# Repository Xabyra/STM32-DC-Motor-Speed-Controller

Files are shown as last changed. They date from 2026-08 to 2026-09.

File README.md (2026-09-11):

# STM32 Sensorless DC Motor Speed Controller (BEMF Feedback)

<p align="center">
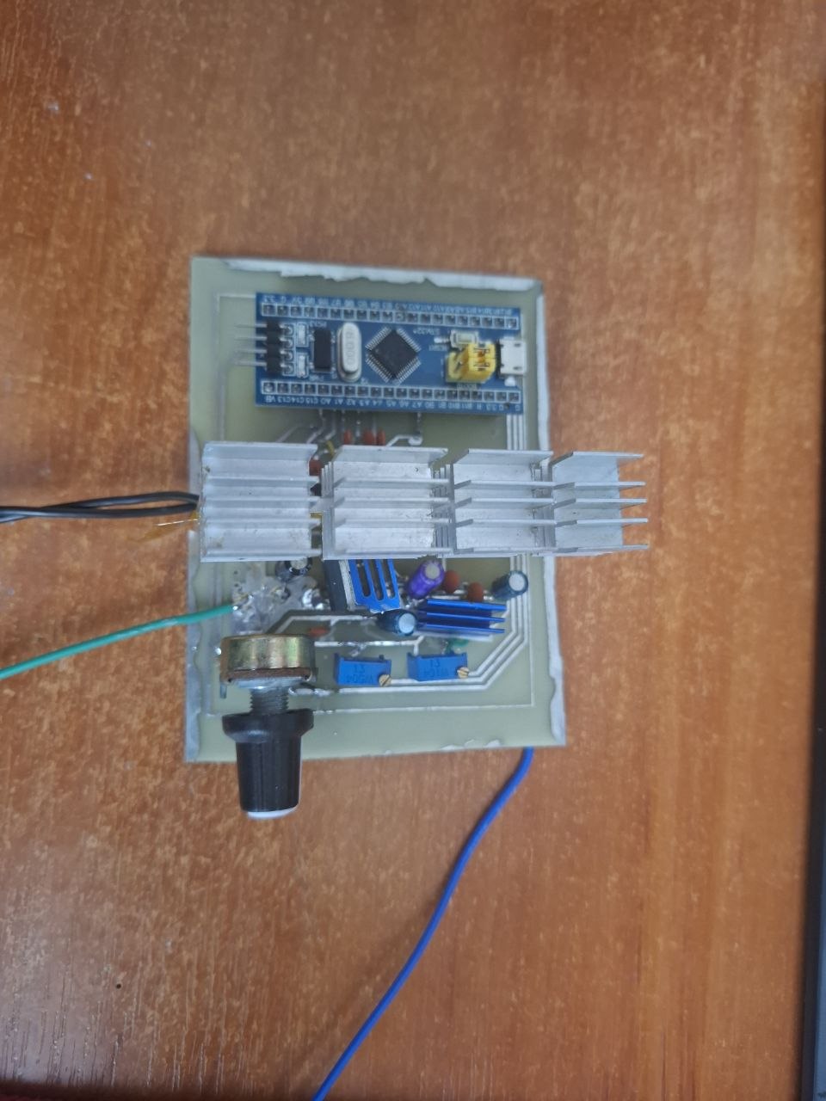
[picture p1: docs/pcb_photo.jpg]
STM32 Motor Controller Board
  
</p>

A closed-loop sensorless brushed DC motor speed regulator using **Back-Electromotive Force (BEMF)** sensing and a digital **PID control algorithm**. Built around the **STM32F103C8** microcontroller with high-speed **SEGGER RTT** real-time telemetry.

---

## ⚡ Key Highlights

* **Sensorless Speed Feedback**: Measures Back-EMF during PWM off-cycles to estimate motor RPM without external optical/magnetic encoders.
* **Closed-Loop PID Regulation**: Real-time RPM stabilization under varying mechanical loads with anti-windup protection.
* **On-the-Fly Tuning**: Live adjustment of PID gains ($K_i$, $K_d$) and target speed via dedicated analog potentiometers.
* **Protection & Smooth Dynamics**: Soft-start speed ramping and undervoltage lockout via continuous motor bus ($V_{MOT}$) monitoring.
* **Non-blocking Telemetry**: High-speed real-time logging via **SEGGER RTT** (J-Link) for control loop inspection without UART latency overhead.

---

## 🛠️ System Overview

### 1. Hardware Architecture (Altium Designer)
Dedicated signal conditioning circuitry with precision resistor dividers for BEMF voltage sensing and power rail filtering.

<p align="center">
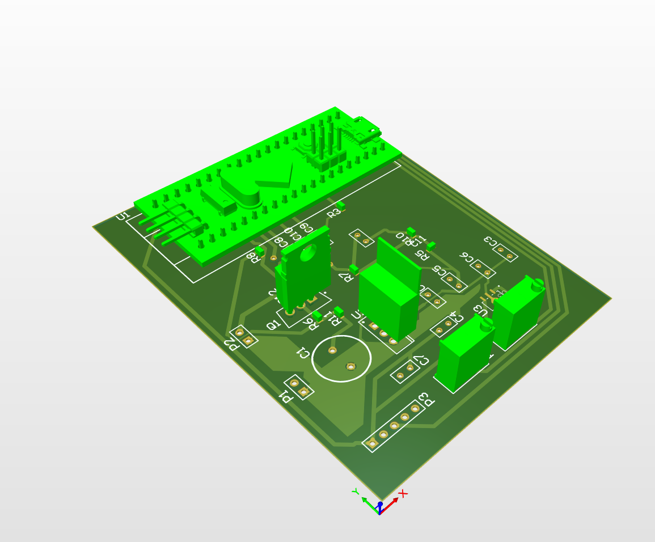
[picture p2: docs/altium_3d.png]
Altium 3D View
  
</p>

* **MCU**: STM32F103C8T6 (ARM Cortex-M3).
* **Power Stage**: H-Bridge motor driver with flyback protection.
* Altium Designer schematics, PCB layouts, and manufacturing Gerbers are located in [`/Hardware`](./Hardware).

---

### 2. Embedded Software (PlatformIO / C++)
* **ADC Sampling**: Synchronized ADC conversions for accurate BEMF and $V_{MOT}$ readings.
* **PWM Generation**: High-frequency timer-driven PWM with configurable duty cycle steps.
* **Control Loop**: Discrete PID controller computing real-time error corrections.

Source code, drivers, and PlatformIO configuration are located in [`/Firmware`](./Firmware).

---

## 📂 Repository Structure

```text
├── Hardware/   # Altium Designer schematics, PCB layout, Gerbers, BOM
├── Firmware/   # PlatformIO source code (C++), drivers, RTT config
└── docs/       # PCB photos, Altium 3D renders, and signal waveforms
```

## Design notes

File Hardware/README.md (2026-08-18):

# DC Motor Regulator with BEMF Feedback
## Software Required

*   **Altium Designer:** You will need Altium Designer (version used for creation or compatible) to open, view, and modify these files.

## Opening the Project

1.  **Install Altium Designer:** Ensure you have Altium Designer installed on your system.
2.  **Clone Repository:** Clone this project to your local machine.
3.  **Open Project File:** Navigate to this `Altium/` directory and open the `.PrjPcb` file (e.g., `DCMotorRegulator.PrjPcb`) using Altium Designer.

## Key Hardware Components

The design typically includes:
*   **STM32F103C8 Microcontroller:** The core processing unit.
*   **Motor Driver:** An H-bridge circuit to control the DC motor (e.g., based on MOSFETs or an integrated driver IC).
*   **Voltage Dividers:** Resistor networks for scaling down the motor voltage (VMOT) and BEMF for ADC input.
*   **Potentiometers:** For user input (target speed, PID tuning).
*   **Power Management:** Voltage regulators to supply the microcontroller and other components.
*   **Connectors:** For motor, power, J-Link, and potentiometers.

## Manufacturing

Once the design is finalized, you can generate manufacturing outputs (Gerber files, NC Drill files, BOM, Pick & Place files) directly from Altium Designer to send to a PCB fabrication house and assembly service.

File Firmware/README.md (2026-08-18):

# Firmware for DC Motor Regulator (PlatformIO)

This directory contains the firmware for the DC Motor Regulator project, developed using PlatformIO with the Arduino framework for the STM32F103C8 microcontroller.

## Project Contents

## Project Overview

The firmware implements the core control logic for regulating a DC motor's speed based on BEMF feedback. It includes:
*   Analog-to-Digital Converter (ADC) readings for BEMF, motor supply voltage (VMOT), target speed, and PID coefficients.
*   Exponential Moving Average (EMA) filters for smoothing sensor readings.
*   A custom PID controller with anti-windup and feedforward capabilities.
*   SEGGER RTT integration for real-time debugging output.

## Requirements

*   **PlatformIO IDE:** Recommended to use the PlatformIO extension for VS Code.
*   **J-Link Debugger:** Required for uploading firmware and utilizing SEGGER RTT.
*   **STM32F103C8 Board:** (e.g., Blue Pill) connected to the J-Link.

## Installation and Setup

1.  **Install PlatformIO:** If you haven't already, install VS Code and the PlatformIO IDE extension.
2.  **Clone Repository:** Clone this project to your local machine.
3.  **Open Project:** Open the `Firmware` directory in VS Code. PlatformIO should automatically detect the project.
4.  **Connect Hardware:**
    *   Connect your STM32F103C8 board to your J-Link debugger (SWD interface).
    *   Ensure the J-Link is connected to your computer.
    *   Refer to the `Docs/Hardware_Connections.md` for detailed wiring instructions.

## Building and Uploading

The `platformio.ini` file is configured for the `genericSTM32F103C8` board and uses `jlink` for upload and debugging.

To build and upload the firmware:
1.  In VS Code, open the PlatformIO sidebar.
2.  Under the "PROJECT TASKS" section for `genericSTM32F103C8`, click on "Build" to compile the code.
3.  After a successful build, click on "Upload" to flash the firmware to your STM32F103C8 board via J-Link.

## SEGGER RTT Debugging

The firmware uses SEGGER RTT for logging and debugging information. This allows you to view real-time output from the microcontroller without halting its execution.

1.  **Start J-Link RTT Viewer:** Open the J-Link RTT Viewer application on your host PC.
2.  **Configure RTT Viewer:**
    *   Select your J-Link device.
    *   Choose "SWD" as the target interface.
    *   Specify the target device (e.g., `STM32F103C8`).
    *   Set the target interface speed (e.g., 4000 kHz).
    *   Click "OK" to connect.
3.  **View Output:** Once connected, you should see the real-time log messages from the microcontroller, including BEMF, target speed, PWM, and PID coefficients.

Example output:
```
RUN | Tar:15000 mV | BEMF:14800 mV | FF:127 | PWM:128/255 | Ki: 50/1000 | Kd: 10/1000
```

## Code Structure (`main.cpp`)

*   **Configuration Defines:** `MAX_TARGET_EMF`, `PID_DIVIDER`, pin assignments, etc.
*   **`IntEMA` Class:** A simple Exponential Moving Average filter for smoothing analog readings.
*   **`PIDreg` Class:** Implements the PID control logic.
*   **`setup()`:** Initializes SEGGER RTT, ADC, PWM, and EMA filters.
*   **`loop()`:** Continuously calls the `control()` function.
*   **`control()`:**
    *   Disables PWM temporarily to measure BEMF.
    *   Reads `VMOT_PIN` and `BEMF_PIN` via voltage dividers.
    *   Filters all analog inputs using EMA.
    *   Calculates PID coefficients from potentiometer readings.
    *   Implements safety checks for `VMOT` and `Target EMF`.
    *   Applies a smooth start to the target speed.
    *   Calculates PWM output using the PID controller and feedforward.
    *   Logs critical data via SEGGER RTT.

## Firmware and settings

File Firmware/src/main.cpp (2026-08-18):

#include <Arduino.h>
#include <SEGGER_RTT.h>

// =========================== CONFIG ===========================
#define MAX_TARGET_EMF 30000  // максимальний BEMF [мВ] 
#define DIV_R1 20000          // верхнє плече дільника [Ом]
#define DIV_R2 2200           // нижнє плече дільника [Ом]
#define PID_DIVIDER 16000.0   

#define MIN_TARGET_EMF 50     // ЗНИЖЕНО: щоб мотор стартував від легкого повороту ручки
#define MIN_VMOT 6000         // мінімальне живлення [мВ] (6В)
#define CTRL_PRD 20           // період управління [мс]
#define WAIT_ADC 800          // пауза після вимкнення ШИМ [мкс]
#define SMOOTH_STEP 100       // крок плавного пуску

#define FIXED_P_RAW 1500      // Фіксований Kp (оскільки ручки зайняті Speed, I, D)

// Піни МК
#define BEMF_PIN  PA0   
#define VMOT_PIN  PA1   
#define SPEED_PIN PA2   // A2 - Скорість (Target)
#define I_PIN     PA3   // A3 - Integral (Ki)
#define D_PIN     PA4   // A4 - Derivative (Kd)
#define PWM_PIN   PB0   

// =========================== DATA ===========================
const int vref = 3300;   // 3.3V
int target = 0;          
int pwm = 0;             

// ========================== IntEMA ==========================
template <typename T>
class IntEMA {
   public:
    T filter(T val, uint8_t k2) {
        T sum = (val - _filt) + _err;
        T div = sum >> k2;
        _err = sum - (div << k2);
        return _filt += div;
    }
    void init(T val) {
        _filt = val;
        _err = 0;
    }
    T get() { return _filt; }
   private:
    T _filt = 0, _err = 0;
};

IntEMA<int> vmot;
IntEMA<int> vemf;
IntEMA<int> a_tar;
IntEMA<int> a_i;
IntEMA<int> a_d;

// =========================== PIDreg ===========================
class PIDreg {
   public:
    float Kp = 0, Ki = 0, Kd = 0;
    float integral = 0;
    float lastError = 0;
    bool firstRun = true;

    int compute(int input, int setpoint, int feedforward, float dt) {
        float error = setpoint - input;
        
        // Інтегральна складова
        float nextIntegral = integral + error * Ki * dt;

        // Диференціальна складова (по похибці)
        float derivative = 0;
        if (!firstRun && dt > 0) {
            derivative = (error - lastError) / dt;
        } else {
            firstRun = false;
        }
        lastError = error;

        // Підсумковий вихід ПІД + FeedForward
        float output = feedforward + (error * Kp) + nextIntegral + (derivative * Kd);

        // Anti-windup (захист інтеграла від переповнення при насиченні PWM)
        if (!((output > 255 && error > 0) || (output < 0 && error < 0))) {
            integral = nextIntegral;
        }

        return constrain((int)output, 0, 255);
    }

    void reset() {
        integral = 0;
        lastError = 0;
        firstRun = true;
    }
};
PIDreg pid;

// =========================== FUNC ===========================

void setPWM(uint8_t duty) {
    analogWrite(PWM_PIN, duty);
}

uint16_t readDivider(uint8_t apin) {
    uint32_t pinMv = (uint32_t)analogRead(apin) * vref / 4096;
    return (pinMv * (DIV_R1 + DIV_R2)) / DIV_R2;
}

void control() {
    static uint32_t tmr;
    if (millis() - tmr < CTRL_PRD) return;
    float dt = (millis() - tmr) / 1000.0f;
    tmr = millis();

    // 1. Вимикаємо ШИМ для заміру BEMF
    setPWM(0);
    delayMicroseconds(WAIT_ADC);

    // 2. Читаємо напруги
    int rawVmot = readDivider(VMOT_PIN);
    int rawMotor = readDivider(BEMF_PIN);
    
    int rawBemf = rawVmot - rawMotor;
    if (rawBemf < 0) rawBemf = 0; 

    // Відновлюємо ШИМ 
    if (rawVmot > MIN_VMOT) setPWM(pwm);

    // 3. Фільтруємо вхідні дані
    vmot.filter(rawVmot, 2);
    vemf.filter(rawBemf, 2);
    a_tar.filter(analogRead(SPEED_PIN), 3);
    a_i.filter(analogRead(I_PIN), 3);
    a_d.filter(analogRead(D_PIN), 3);

    int newTarget = (long)a_tar.get() * MAX_TARGET_EMF / 4096;

    // Розрахунок коефіцієнтів з потенціометрів
    pid.Kp = (float)FIXED_P_RAW / PID_DIVIDER;
    pid.Ki = (float)a_i.get() / PID_DIVIDER;
    pid.Kd = (float)a_d.get() / PID_DIVIDER;

    // 4. ПЕРЕВІРКА ЗАХИСТІВ
    if (rawVmot <= MIN_VMOT) {
        SEGGER_RTT_printf(0, "[BLOCKED] VMOT too low: %d mV\r\n", rawVmot);
        pid.reset(); target = 0; pwm = 0; setPWM(0);
        return;
    }
    
    if (newTarget < MIN_TARGET_EMF) {
        SEGGER_RTT_printf(0, "[BLOCKED] Target too low: %d mV (Pot: %d)\r\n", newTarget, a_tar.get());
        pid.reset(); target = 0; pwm = 0; setPWM(0);
        return;
    }

    // 5. Плавний пуск та розрахунок
    target += constrain(newTarget - target, -SMOOTH_STEP, SMOOTH_STEP);

    int current_vmot = vmot.get();
    if (current_vmot < 1000) current_vmot = 1000; 

    int feedforward = (long)target * 255 / current_vmot;

    pwm = pid.compute(vemf.get(), target, feedforward, dt);
    setPWM(pwm);

    // 6. УСПІШНИЙ ЛОГ РОБОТИ
    SEGGER_RTT_printf(0, "RUN | Tar:%d mV | BEMF:%d mV | FF:%d | PWM:%d/255 | Ki: %d/1000 | Kd: %d/1000\r\n", 
                      target, vemf.get(), feedforward, pwm, (int)(pid.Ki * 1000), (int)(pid.Kd * 1000));
}

void setup() {
    SEGGER_RTT_Init();
    SEGGER_RTT_WriteString(0, "\r\n=== BEMF PID Controller Started ===\r\n");

    analogReadResolution(12);
    pinMode(PWM_PIN, OUTPUT);
    analogWriteResolution(8); 
    analogWriteFrequency(16000); 

    int startVmot = readDivider(VMOT_PIN);
    vmot.init(startVmot > 0 ? startVmot : 12000);
    vemf.init(0);
}

void loop() {
    control();
}

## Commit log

2026-08-18 Initial commit: complete hardware design and closed-loop firmware
    [DCMotorContolMarathon.PrjPcb, MainBoard.SchDoc, PCB1.PcbDoc]
2026-08-18 Add title for DC Motor Regulator project
2026-08-18 Revise README for STM32 Motor Speed Controller
    Updated project title and enhanced feature descriptions for clarity. Added key highlights and improved project structure overview.
